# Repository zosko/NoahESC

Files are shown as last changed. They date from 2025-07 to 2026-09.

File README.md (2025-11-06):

# NoahESC
The Atmega8-based Electronic Speed Controller (ESC) is a motor control device that uses the Atmega8 microcontroller as its main processing unit. It is designed to regulate the speed, direction, and braking of brushless DC (BLDC) motors or brushed motors, depending on the application. The Atmega8 handles the input signals—typically from a flight controller or receiver—and converts them into precise pulse-width modulation (PWM) outputs to control the motor’s performance. This type of ESC is widely used in drones, RC vehicles, and robotics projects due to its reliability, programmability, and compatibility with open-source firmware such as TGY. Overall, it provides an efficient and flexible solution for motor speed control in embedded and hobbyist applications.

### Features
- [X] PWM
- [X] 30Amps
- [X] 2 - 4S battery
- [X] Low cost

## Scheme
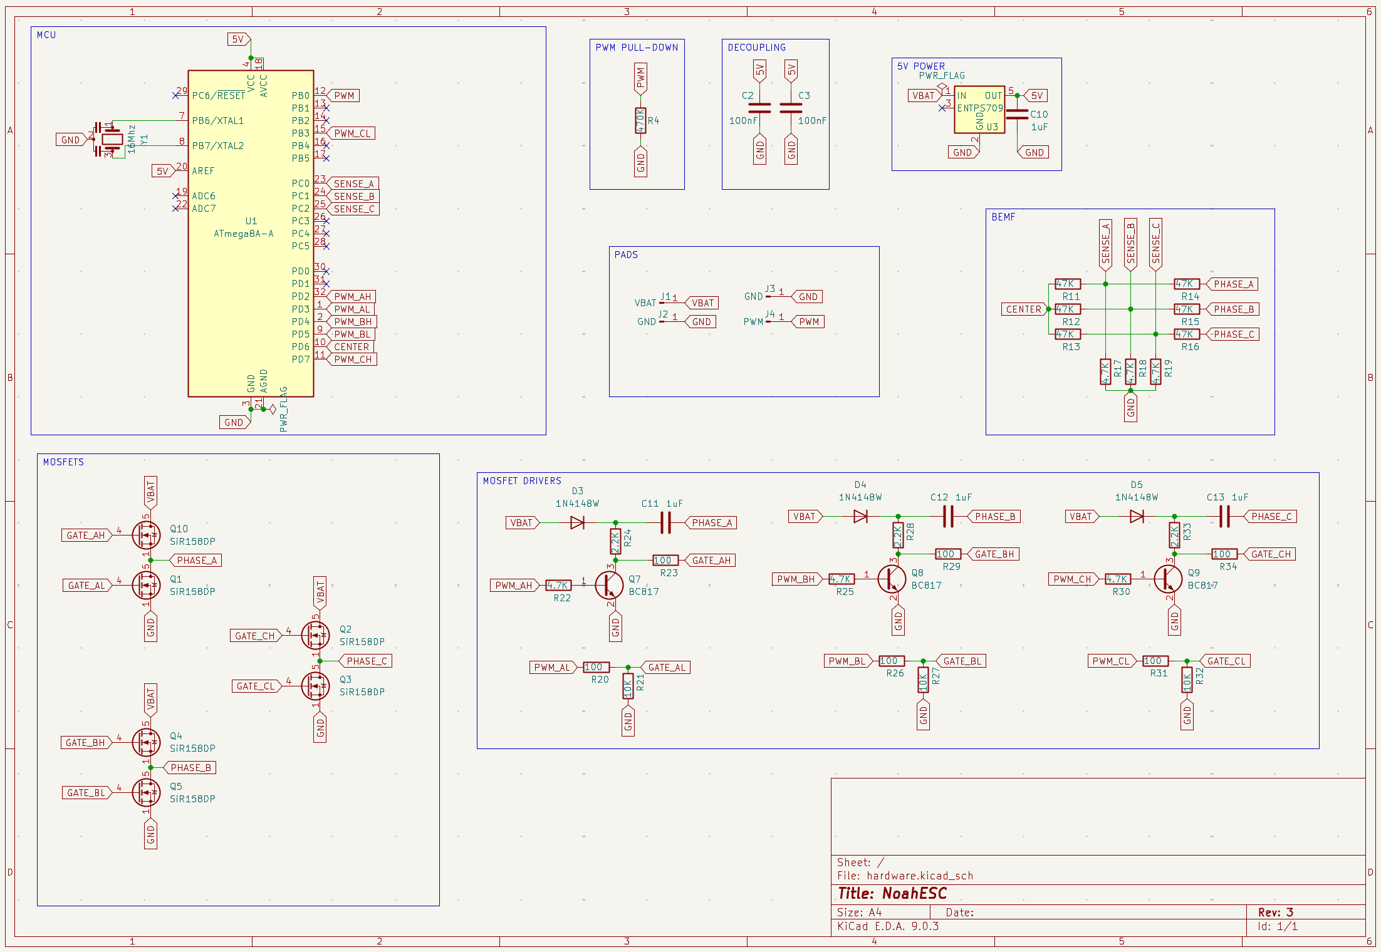
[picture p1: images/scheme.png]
Scheme


## Boards Preview
Board|PCB
---------|---------
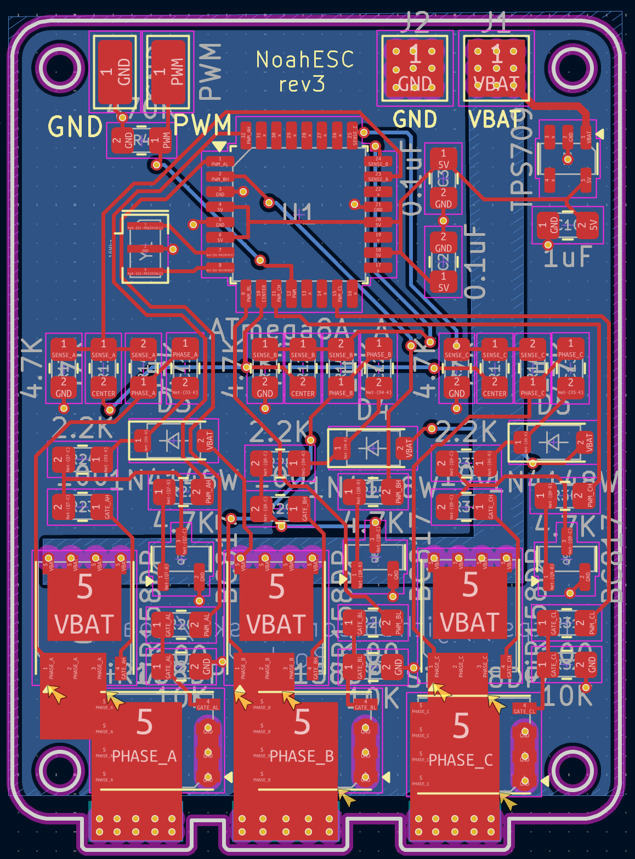
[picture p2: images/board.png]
Board
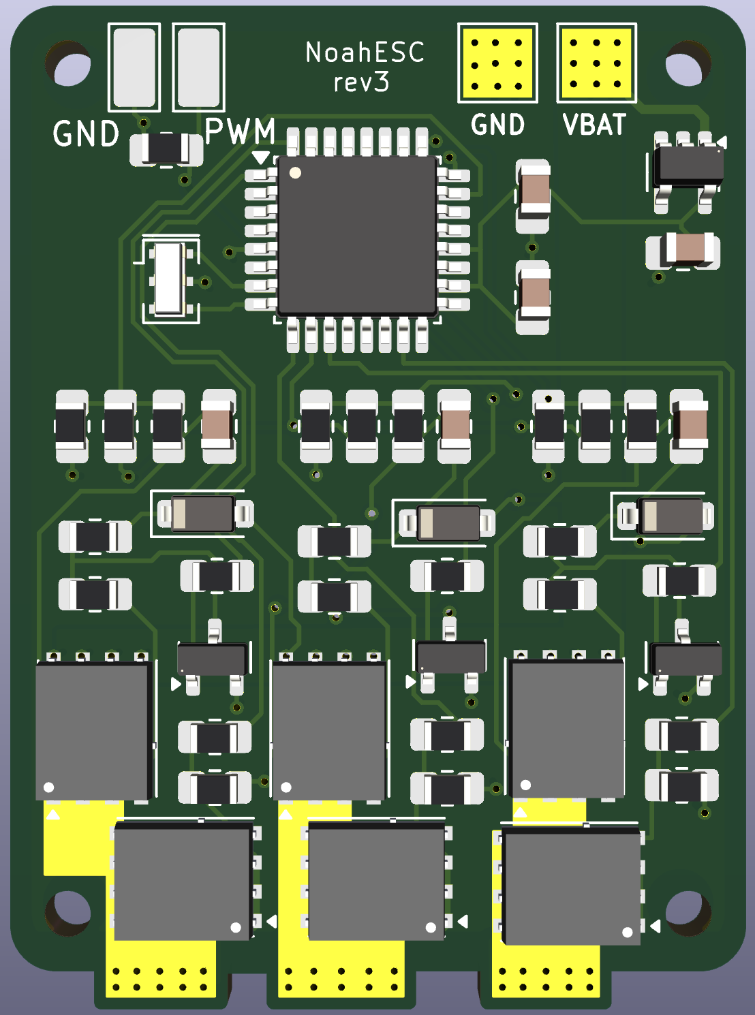
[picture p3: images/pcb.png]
View 1
|

### Flashing
Atmega8 must be flashed via ICSP microcontroller pins. 

**Arduino UNO as ISP programmer**
- `avrdude -c stk500v1 -p m8 -P /dev/tty.usbmodem14401 -b 19200 -U flash:w:firmware.hex:i`
- `avrdude -c stk500v1 -p m8 -P /dev/tty.usbmodem14401 -b 19200 -U lfuse:w:0x3f:m -U hfuse:w:0xca:m`

**USBasp**
- `avrdude -c usbasp -p m8 -U flash:w:firmware.hex:i`
- `avrdude -c usbasp -p m8 -U lfuse:w:0x3f:m -U hfuse:w:0xca:m`

**Download**: [Firmware](firmware.hex)

## PCB Design

PCBWay_logo

**Huge thanks to [PCBWay](https://pcbway.com) for sponsoring this project!**

PCBWay is a leading provider of high-quality printed circuit boards (PCBs), offering reliable and affordable solutions for both hobbyists and professionals. Their services include rapid prototyping, PCB assembly, instant online quotations, expert design verification, and a streamlined ordering experience.

Their comprehensive range of services includes:
- PCB prototyping
- Assembly services
- Instant online quotations
- Expert design verification
- A streamlined, user-friendly ordering system

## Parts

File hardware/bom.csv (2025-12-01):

Reference | Value | LCSC
C2,C3 | 100nF | C49678
C10,C11,C12,C13 | 1uF | C28323
D3,D4,D5 | 1N4148W | C241939
J1 | VBAT
J2,J3 | GND
J4 | PWM
J5 | Programming | C22438289
Q1,Q2,Q3,Q4,Q5,Q10 | SiR158DP | C142530
Q7,Q8,Q9 | BC817 | C39828
R4 | 470K | C89104
R11,R12,R13,R14,R15,R16 | 47K | C17713
R17,R18,R19,R22,R25,R30 | 4.7K | C17673
R20,R23,R26,R29,R31,R34 | 100 | C17408
R21,R27,R32 | 10K | C84376
R24,R28,R33 | 2.2K | C17520
U1 | ATmega8A-A | C16190
U3 | TPS709 | C2865456
Y1 | 16Mhz | C882606

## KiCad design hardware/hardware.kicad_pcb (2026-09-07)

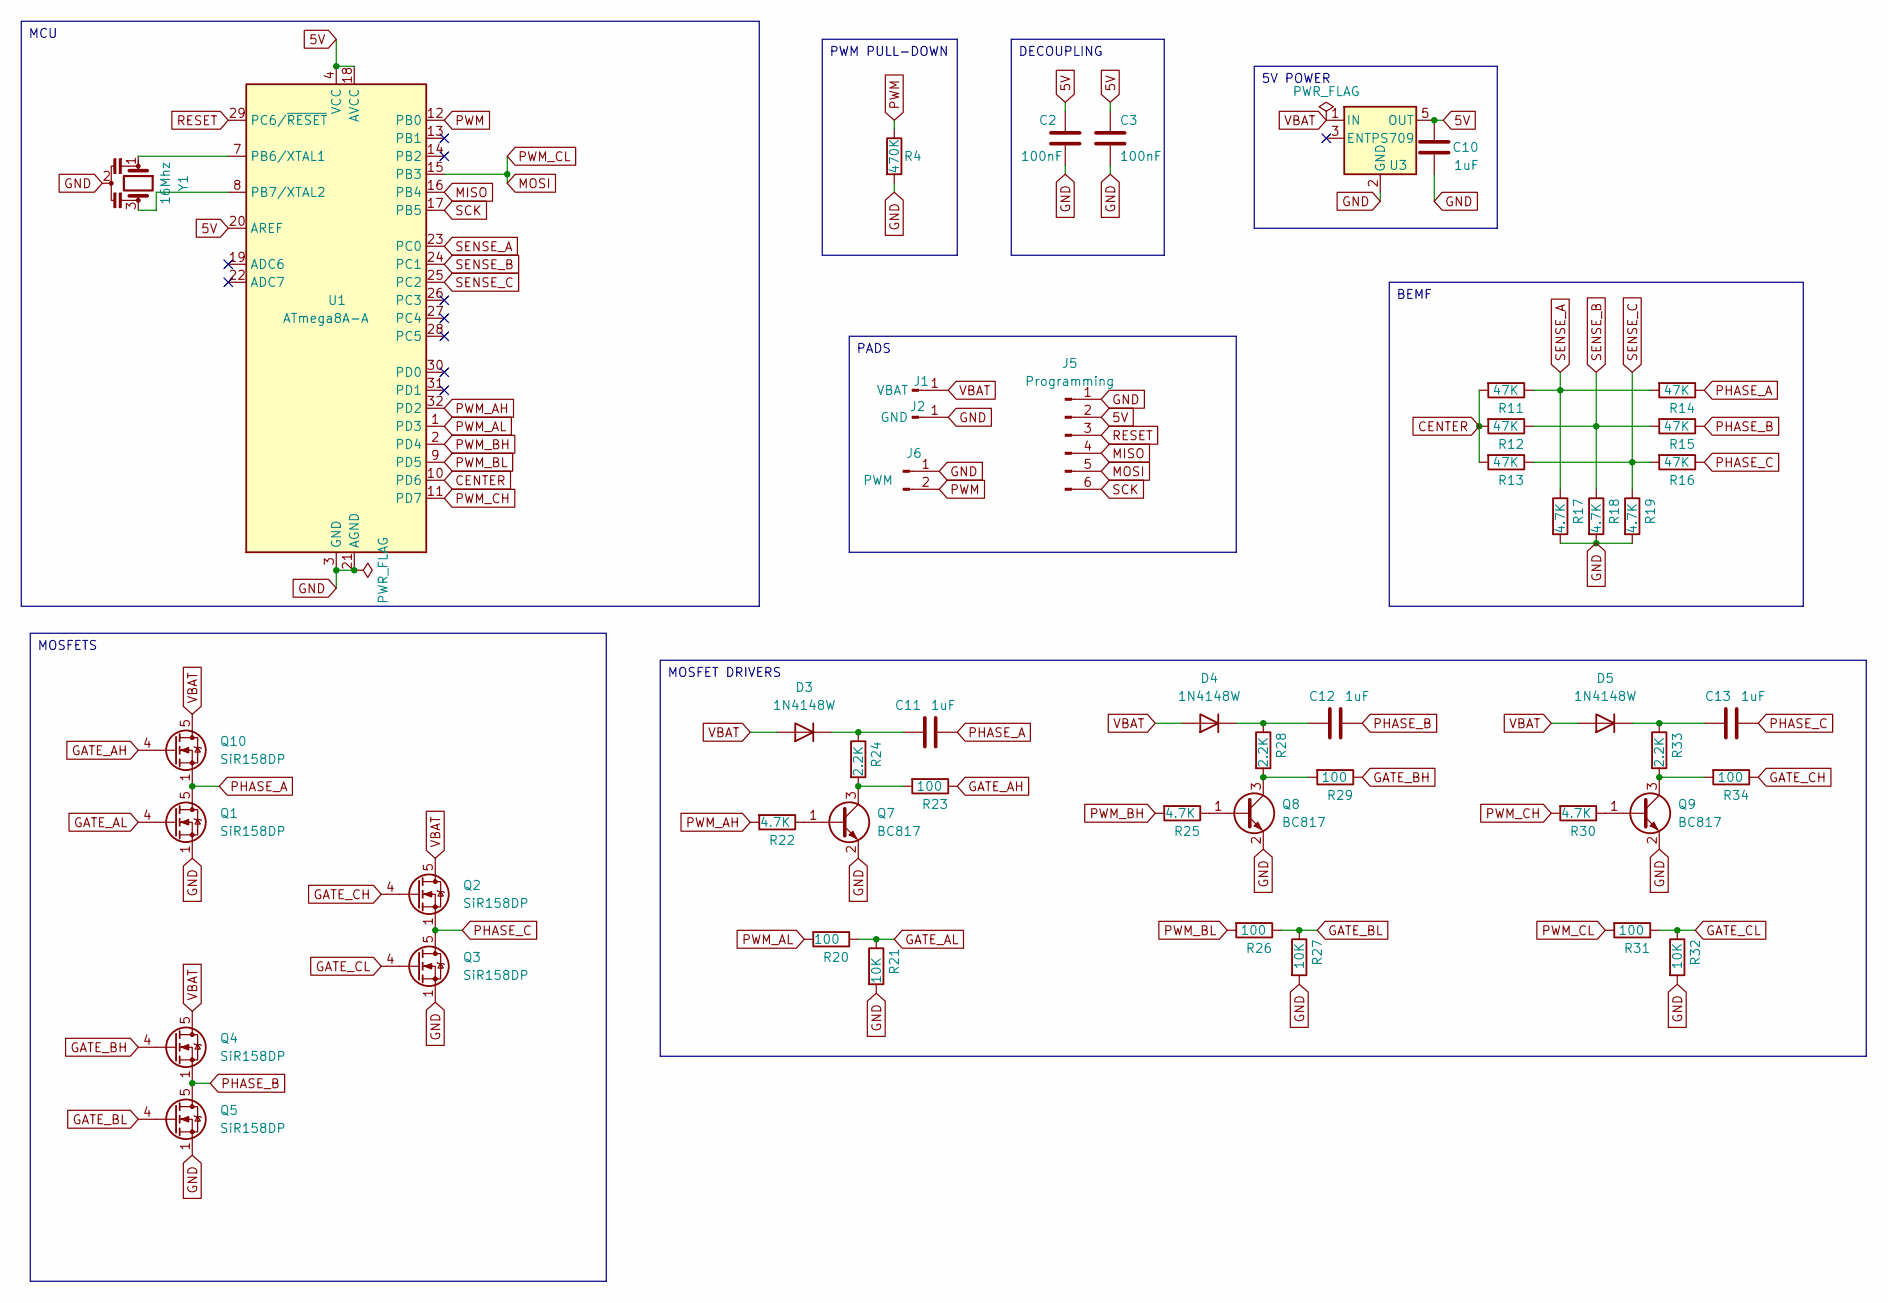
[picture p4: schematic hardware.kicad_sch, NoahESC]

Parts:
C2, C3: 100nF; C_0805_2012Metric_Pad1.18x1.45mm_HandSolder; LCSC C49678
C10, C11, C12, C13: 1uF; C_0805_2012Metric_Pad1.18x1.45mm_HandSolder; LCSC C28323
D3, D4, D5: 1N4148W; D_SOD-123; LCSC C241939
J1: VBAT; TestPoint_Pad_3.0x3.0mm
J2: GND; TestPoint_Pad_3.0x3.0mm
J5: Programming; PinHeader_1x06_P1.27mm_Vertical; LCSC C22438289
J6: PWM; PinHeader_1x02_P2.54mm_Vertical; LCSC C42431798
Q1, Q2, Q3, Q4, Q5, Q10: SiR158DP; PowerPAK_SO-8_Single; LCSC C142530
Q7, Q8, Q9: BC817; SOT-23; LCSC C39828
R4: 470K; R_0805_2012Metric_Pad1.20x1.40mm_HandSolder; LCSC C89104
R11, R12, R13, R14, R15, R16: 47K; R_0805_2012Metric_Pad1.20x1.40mm_HandSolder; LCSC C17713
R17, R18, R19, R22, R25, R30: 4.7K; R_0805_2012Metric_Pad1.20x1.40mm_HandSolder; LCSC C17673
R20, R23, R26, R29, R31, R34: 100; R_0805_2012Metric_Pad1.20x1.40mm_HandSolder; LCSC C17408
R21, R27, R32: 10K; R_0805_2012Metric_Pad1.20x1.40mm_HandSolder; LCSC C84376
R24, R28, R33: 2.2K; R_0805_2012Metric_Pad1.20x1.40mm_HandSolder; LCSC C17520
U1: ATmega8A-A; TQFP-32_7x7mm_P0.8mm; LCSC C16190
U3: TPS709; SOT-23-5; LCSC C2865456
Y1: 16Mhz; Resonator_SMD_Murata_CSTxExxV-3Pin_3.0x1.1mm; LCSC C882606

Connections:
5V: C2.1, C3.1, C10.2, J5.2, U1.4 (VCC), U1.6 (VCC), U1.18 (AVCC), U1.20 (AREF), U3.5 (OUT)
CENTER: R11.2, R12.2, R13.2, U1.10 (PD6)
GATE_AH: Q10.4 (G), R23.1
GATE_AL: Q1.4 (G), R20.1, R21.1
GATE_BH: Q4.4 (G), R29.1
GATE_BL: Q5.4 (G), R26.1, R27.1
GATE_CH: Q2.4 (G), R34.1
GATE_CL: Q3.4 (G), R31.1, R32.1
GND: C2.2, C3.2, C10.1, J2.1, J5.1, J6.1, Q1.1 (S), Q1.2 (S), Q1.3 (S), Q3.1 (S), Q3.2 (S), Q3.3 (S), Q5.1 (S), Q5.2 (S), Q5.3 (S), Q7.2 (E), Q8.2 (E), Q9.2 (E), R4.2, R17.2, R18.2, R19.2, R21.2, R27.2, R32.2, U1.3 (GND), U1.5 (GND), U1.21 (AGND), U3.2 (GND), Y1.2
MISO: J5.4, U1.16 (PB4)
MOSI: J5.5, R31.2, U1.15 (PB3)
unnamed: C11.2, D3.1 (K), R24.1
unnamed: C12.2, D4.1 (K), R28.1
unnamed: C13.2, D5.1 (K), R33.1
unnamed: Q7.1 (B), R22.1
unnamed: Q7.3 (C), R23.2, R24.2
unnamed: Q8.1 (B), R25.1
unnamed: Q8.3 (C), R28.2, R29.2
unnamed: Q9.1 (B), R30.1
unnamed: Q9.3 (C), R33.2, R34.2
unnamed: U1.7 (PB6/XTAL1), Y1.1
unnamed: U1.8 (PB7/XTAL2), Y1.3
PHASE_A: C11.1, Q1.5 (D), Q10.1 (S), Q10.2 (S), Q10.3 (S), R14.1
PHASE_B: C12.1, Q4.1 (S), Q4.2 (S), Q4.3 (S), Q5.5 (D), R15.1
PHASE_C: C13.1, Q2.1 (S), Q2.2 (S), Q2.3 (S), Q3.5 (D), R16.1
PWM: J6.2, R4.1, U1.12 (PB0)
PWM_AH: R22.2, U1.32 (PD2)
PWM_AL: R20.2, U1.1 (PD3)
PWM_BH: R25.2, U1.2 (PD4)
PWM_BL: R26.2, U1.9 (PD5)
PWM_CH: R30.2, U1.11 (PD7)
RESET: J5.3, U1.29 (PC6/~RESET)
SCK: J5.6, U1.17 (PB5)
SENSE_A: R11.1, R14.2, R17.1, U1.23 (PC0)
SENSE_B: R12.1, R15.2, R18.1, U1.24 (PC1)
SENSE_C: R13.1, R16.2, R19.1, U1.25 (PC2)
VBAT: D3.2 (A), D4.2 (A), D5.2 (A), J1.1, Q2.5 (D), Q4.5 (D), Q10.5 (D), U3.1 (IN)

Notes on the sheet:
MCU
BEMF
5V POWER
PADS
DECOUPLING
MOSFET DRIVERS
PWM PULL-DOWN
MOSFETS

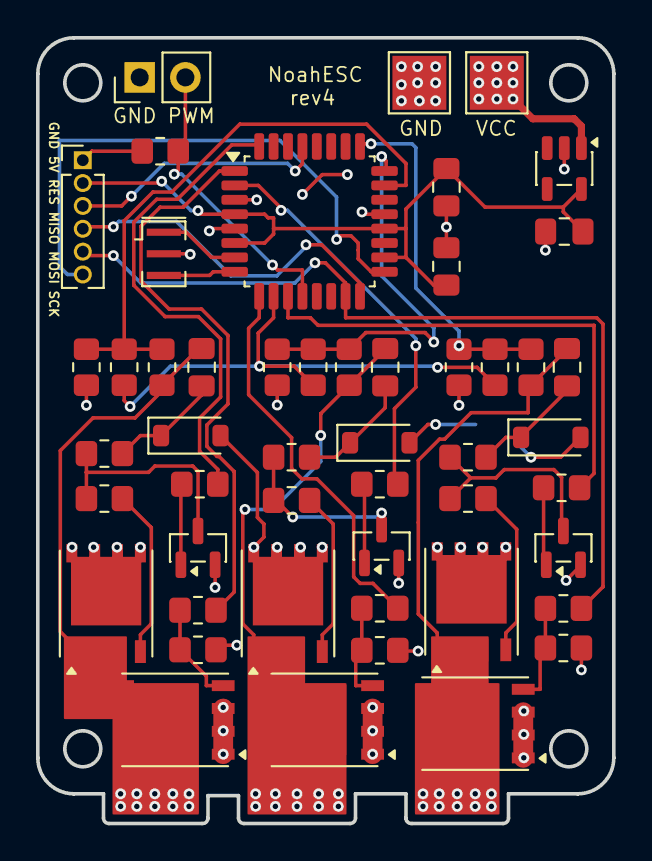
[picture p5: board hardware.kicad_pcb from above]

Board: 2 copper layers, 32.0 x 43.7 mm, 50 parts (0 on the bottom side), 37 nets.

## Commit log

2022-08-02 fix pcb
    [NoahESC.kicad_pcb]
2022-10-01 rename folder
    [NoahESC.kicad_pcb, NoahESC.kicad_sch]
2022-12-23 experimental version
    [NoahESC.kicad_pcb, NoahESC.kicad_sch]
2023-06-27 DIP version
    [NoahESC.kicad_pcb, NoahESC.kicad_sch]
2023-11-30 remove experimental
    [NoahESC.kicad_pcb, NoahESC.kicad_sch]
2023-11-30 update project to rev1
    [NoahESC.kicad_pcb, NoahESC.kicad_sch, hardware.kicad_pcb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]
2023-11-30 additional vcc / gnd
    [hardware.kicad_pcb, hardware.kicad_sch]
2024-02-28 update to kicad 8
    [hardware.kicad_pcb, hardware.kicad_sch]
2024-03-04 add rev1 board - single side
    [hardware.kicad_pcb, hardware.kicad_sch]
2024-04-16 add rev2
    [hardware.kicad_pcb, hardware.kicad_sch]
2024-04-20 add solder mask on bottom plate
    [hardware.kicad_pcb]
2024-07-02 rename capacitors
    [hardware.kicad_pcb, hardware.kicad_sch]
2025-07-31 update rev3 board
    [hardware.kicad_pcb, hardware.kicad_sch]
2025-12-01 add bom file
    [bom.csv]
2025-12-01 add rev4
    [hardware.kicad_pcb, hardware.kicad_sch]
2025-12-04 add new pwm pin
    [hardware.kicad_pcb, hardware.kicad_sch]
